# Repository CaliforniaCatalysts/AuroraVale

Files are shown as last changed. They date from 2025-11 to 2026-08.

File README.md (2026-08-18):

# Converting a 3D Printer Into an Automatic Spray Coater
aa4b74ef-185c-4f39-813c-6c8934d8dcba
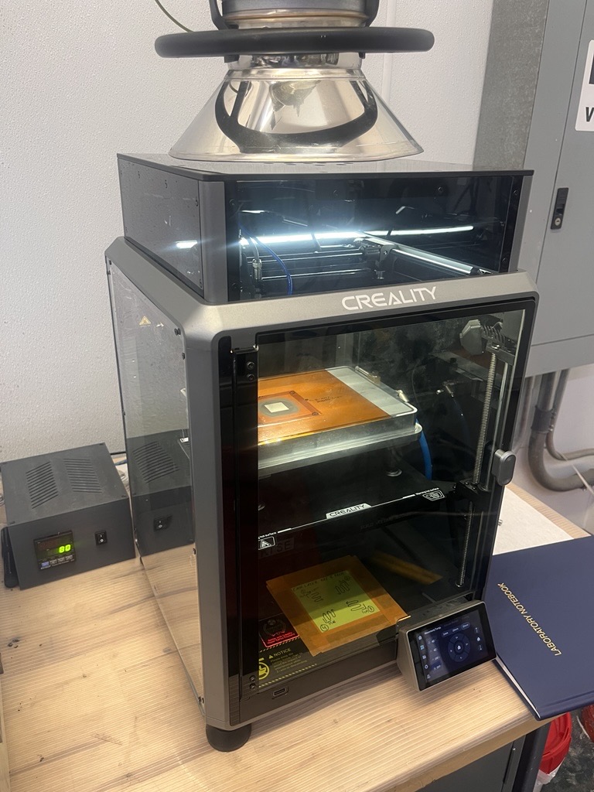
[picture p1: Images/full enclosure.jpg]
aa4b74ef-185c-4f39-813c-6c8934d8dcba

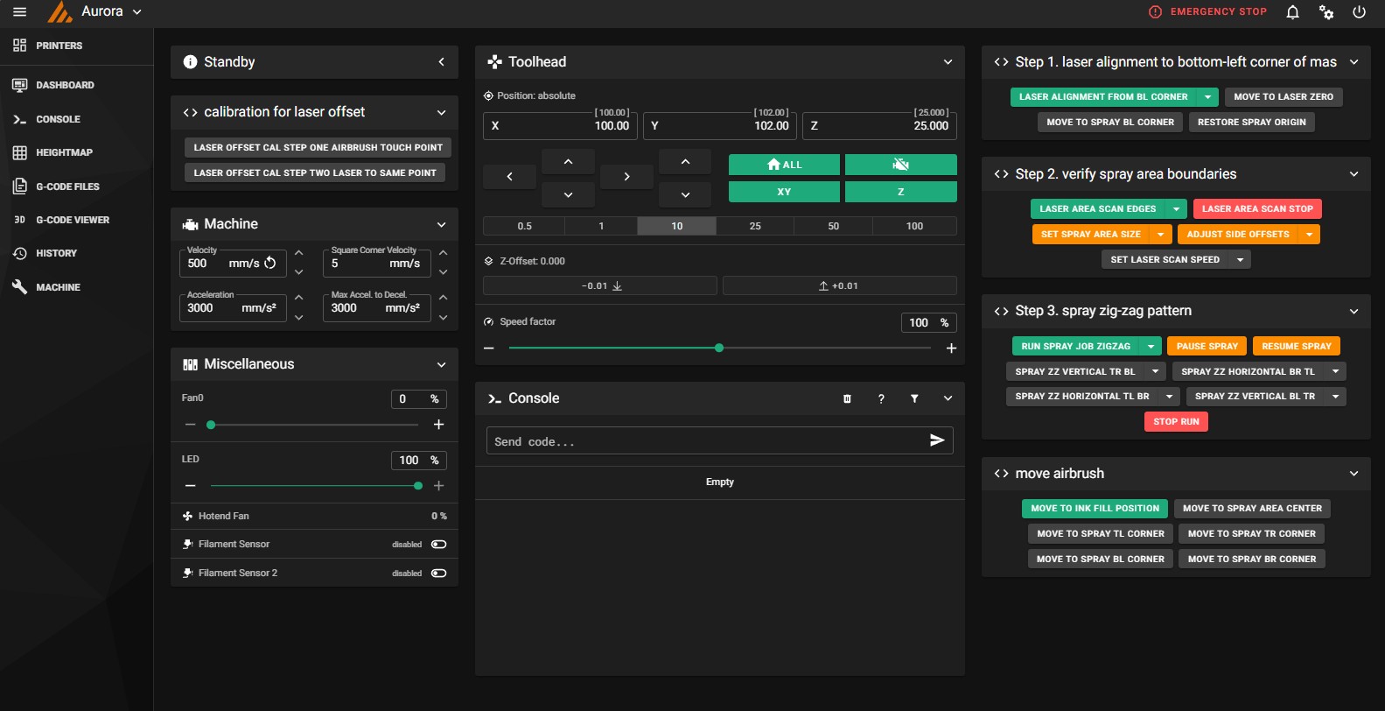
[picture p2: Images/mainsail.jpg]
mainsail web interface


This project was developed at Calicat by Steven Jaffe-Lewis, Nadia E.Tolouei, and Que Nhi Nguyen beginning in Summer 2025. 
All files and code are being released under MIT license. The team hopes that this project will be useful for other electrochemistry labs to standardize this manual airbrush process and improve loading uniformity of sprayed catalyst inks for making catalyst-coated membranes or related components.

inspired from Remi_Rafael's project: https://www.instructables.com/Converting-a-3D-Printer-Into-an-Automatic-Spray-Co/

Main changes by the team at Calicat:
 - improved the airbrush button actuation consistency and angle resolution by moving the servo arm rotation to be planar with the airbrush trigger.
 - updated stl files for mounting the airbrush onto a Creality K1 printer.
 - parameterized the spray area and path through klipper macros, enabling adjustments from within the mainsail interface.
 - added a laser crosshair used for sewing machines to precisely align the airbrush nozzle with the desired mask area.
 - built the web interface using Mainsail to control the equipment.
 - added a heated microporous vacuum board as the base.

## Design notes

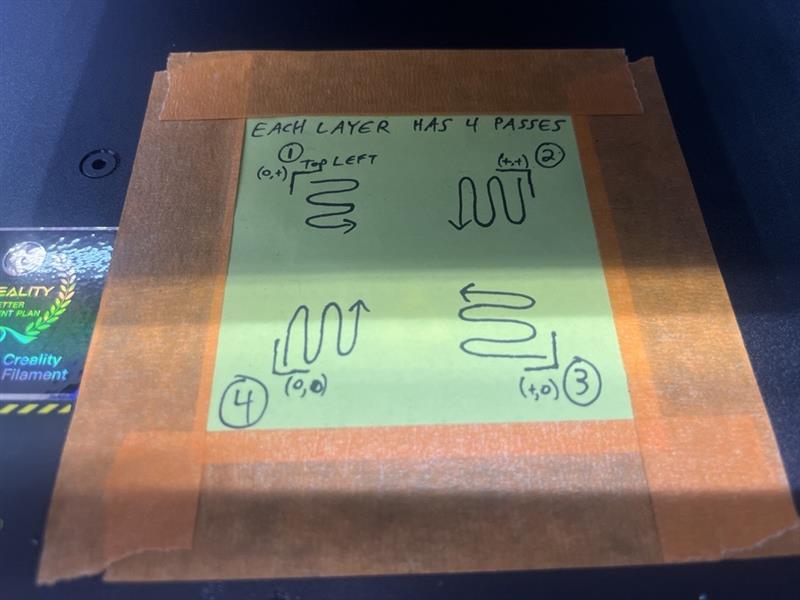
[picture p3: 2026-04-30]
Images/6f3b2e6d-e895-4d3d-af6d-b4a39b8a7106.jpg

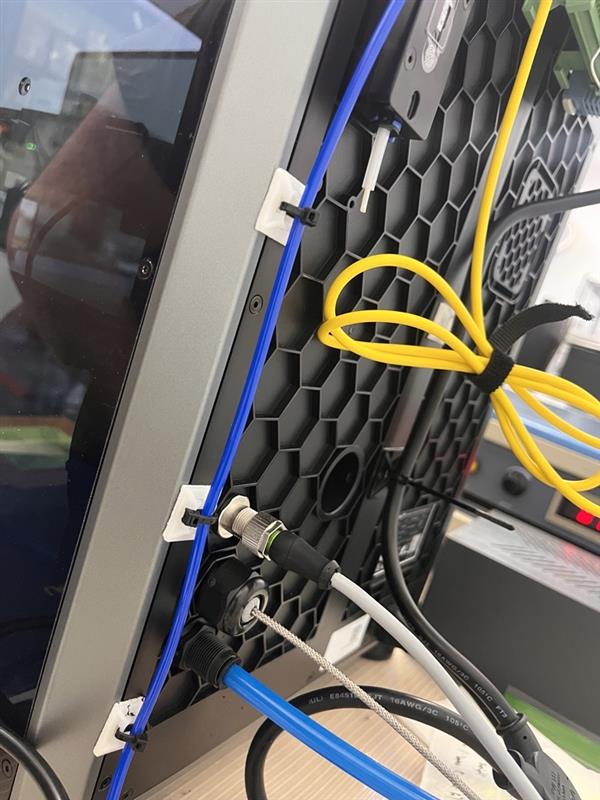
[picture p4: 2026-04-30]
Images/cb442da4-e796-43ce-a95e-fac4f4cbbab6.jpg

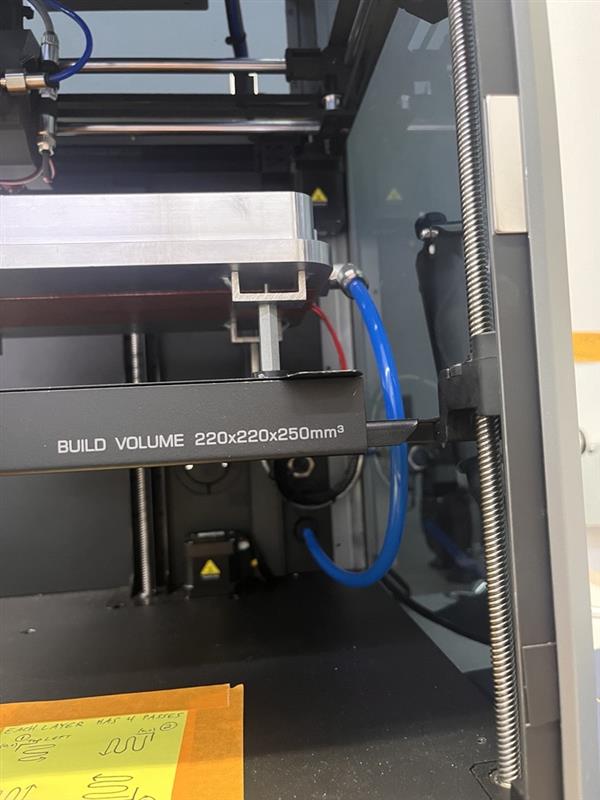
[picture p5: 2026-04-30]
Images/b7cdc5cb-0d74-4510-bfb3-8b063ddc7fe8.jpg

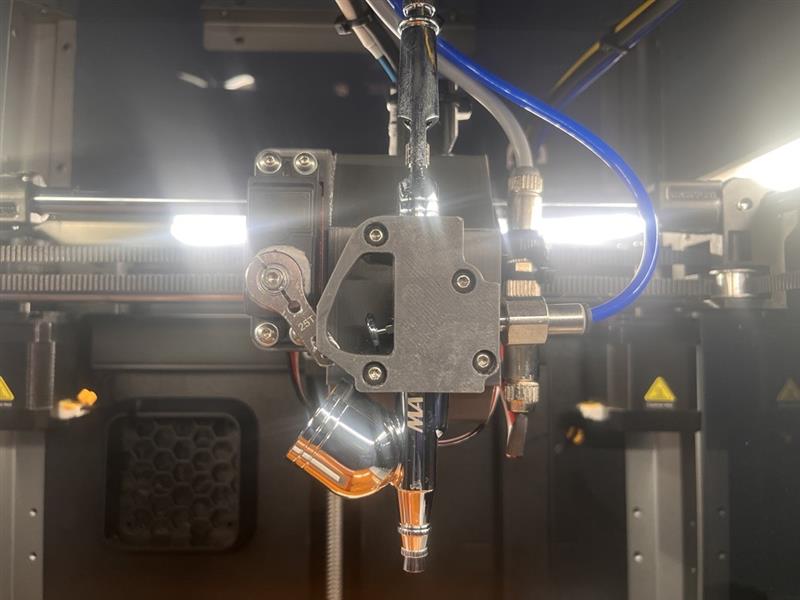
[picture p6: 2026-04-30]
Images/aa4b74ef-185c-4f39-813c-6c8934d8dcba.jpg

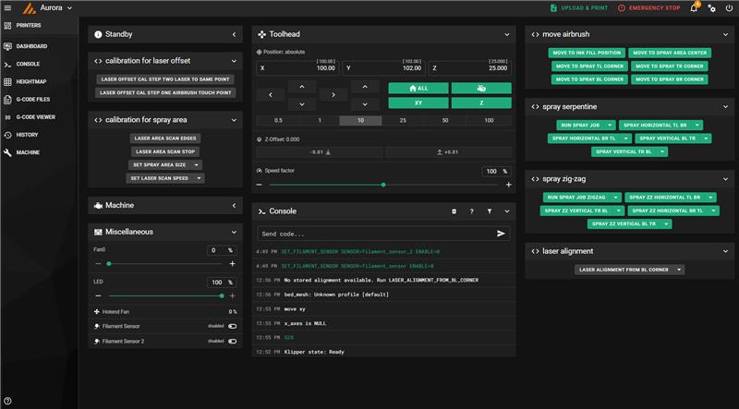
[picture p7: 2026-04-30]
Images/abf6030a-79bf-4fd6-ab85-4bce50de7b40.jpg

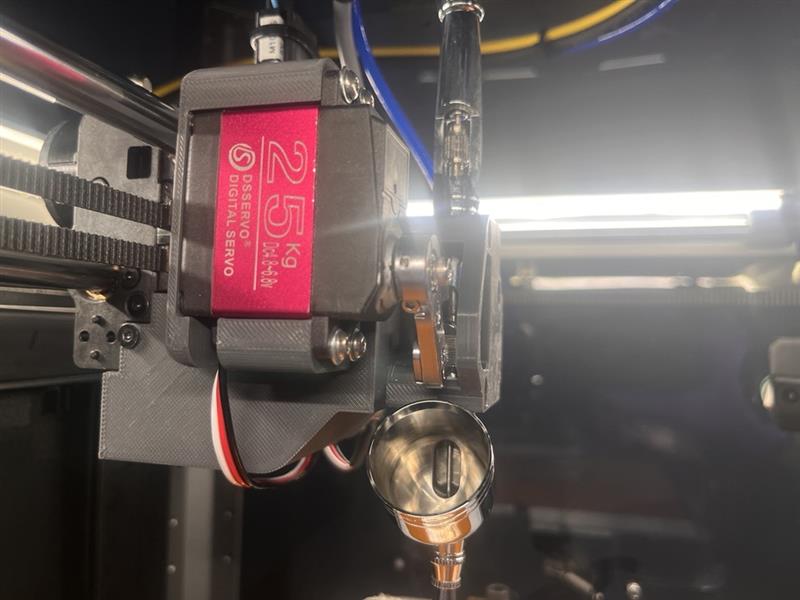
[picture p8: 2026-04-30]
Images/523d340f-f855-4a28-a0e2-c79435cb36b6.jpg

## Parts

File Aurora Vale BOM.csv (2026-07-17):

Nadia's and Nhi's Summer 2025 internship
3D Printer Modified Air Brush Spraying
Item Category | Description | Supplier | Part Number | Manufacturer | Model | Design Component | Qty Needed to Order | Unit Price | Comment | Order Status | ETA | Purchase Link
Connections | Chemical-Resistant Plastic Tubing | Mcmaster | 9388T11 |  |  |  | 10 ft | $2.70 | 1/8" ID, 1/4" OD, FEP clear tubing
Connections | Dupont Connetor |  |  |  |  | 1 | 1 | $6.98 | 40pin Male to Male, 40pin Female to Female Breadboard Jumper Ribbon Cables |  |  | https://www.amazon.com/Elegoo-EL-CP-004-Multicolored-Breadboard-arduino/dp/B01EV70C78
Control | Arduino | Amazon | A000066 |  | Arduino Elegoo Uno R3 | 2 | 1 | $13.99 | ATmega328P Microcontroller, USB-B, 7-12V input voltage |  |  | https://www.amazon.com/ELEGOO-Controller-ATmega328P-Compatible-Arduino/dp/B0B6VV7MS7
Control | Relay | DigiKey | 2066-46.61.9.024.0040-ND | Finder Relays, Inc. | 46.61.9.024.0040 |  |  | $8.43 | Relay Gen Purpose SPDT 16A 24 VDC
Control | Sensor
Control | Thermocouple | Mcmaster |  |  |  |  |  |  | Resistance Temperature Detector (RTD)
Equipment | 3D Printer | Amazon |  | Creality | K1 SE | 1 | 1 | $259.61 | Dimention 355x355x482mm, open frame, open-source | Ordered | 28-Jul | https://a.co/d/5Y77dD0
Equipment | Camera for 3D printer | Amazon |  | Creality | K1 AI | 1 | 1 | $25.23 |  | Ordered | 28-Jul | https://a.co/d/2F8gHx9
Equipment | Vacuum Table | Clampus | MP2216M | Clampus |  | 1 | 0 | $484.33 |  | In stock |  | Vacuum Table MP2216M - 8.66 x 6.30 in. - ClampuSystems
Equipment | Control Heater |  |  |  |  | 1 | 1 |  |  | Ordered
Equipment | DC/DC converter | Amazon |  | HiLetgo | LM2596 DC-DC | 1 |  | $10.48 | Adjustable DC/DC step down converter 4.0-40V to 1.25-37V |  |  | https://www.amazon.com/HiLetgo-Step-down-Converter-1-25-37V-Voltmeter/dp/B00LSEBYHU/ref=sr_1_8?
Equipment | Airbrush | Amazon |  |  | G233 Pro | 1 | 1 | $39.99 | 0.2, 0.3 & 0.5mm Needles, 1/3 oz Cup |  |  | https://www.amazon.com/Master-Airbrush-Multi-Purpose-Dual-Action-Professional/dp/B002KJDXHQ
Equipment | Compressor | Amazon |  | TIMBERTECH | AS18-2 |  | 1 | $66.79 | 120 VAC, 4 bar Auto Stop |  |  | https://www.amazon.com/dp/B07VSFZVRH?sp_csd=d2lkZ2V0TmFtZT1zcF9kZXRhaWxfdGhlbWF0aWM
Equipment | DC Servo Motor | DigiKey | 1738-SER0064-ND | DFRobot | SER0064 | 2 |  | $21.90 | Positional Rotation DC Motor Gearmotor 52 RPM 5 ~ 8.4VDC | Ordered |  | https://www.digikey.com/en/products/detail/dfrobot/SER0064/23028651
Miscellaneous | LED light stip | Amazon |  |  |  | 1 | 16.4 ft | $19.99 | Uniform Light 9W, 480LED/m, Cool White, IP65 (water resistance), 24 VDC |  |  | https://www.amazon.com/gp/product/B08VWXPQYP/ref=ox_sc_act_title_4?smid=A35UAT07QG3EC6&th=1
 |  |  |  |  |  |  |  | $960.42

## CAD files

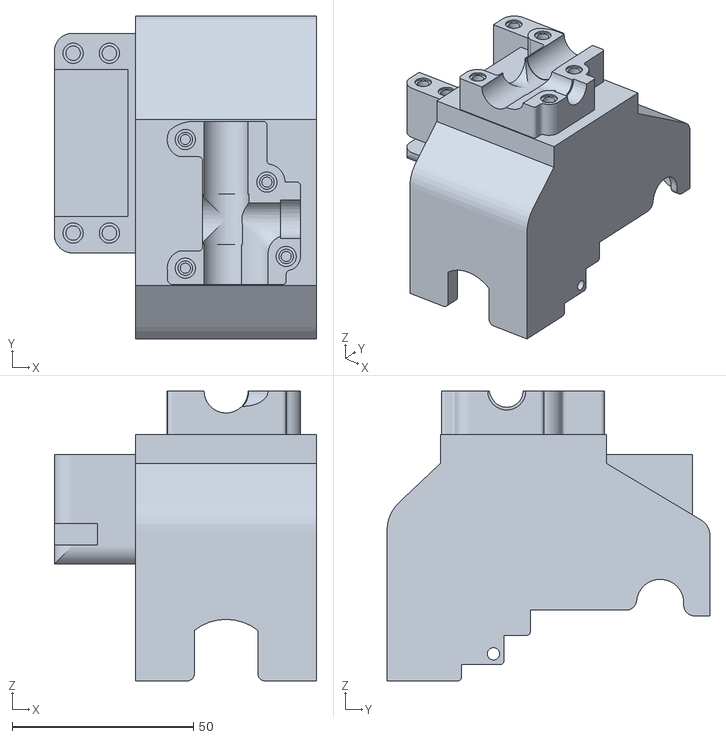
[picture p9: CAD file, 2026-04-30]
Airbrush_mount/Airbrush_mount_STLfiles/Airbrush Mount Assembly.STL
72.4 x 89.1 x 80.0

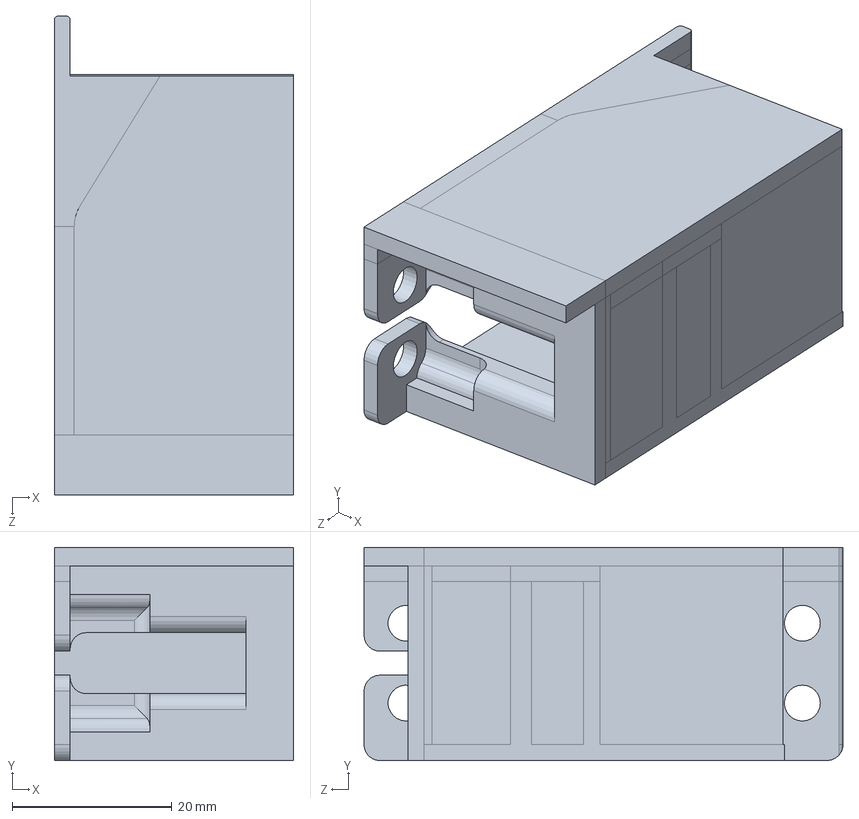
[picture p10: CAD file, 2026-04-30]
Airbrush_mount/Airbrush_mount_Solidworks/Servo Mount.SLDPRT
30.0 x 26.7 x 60.0 mm

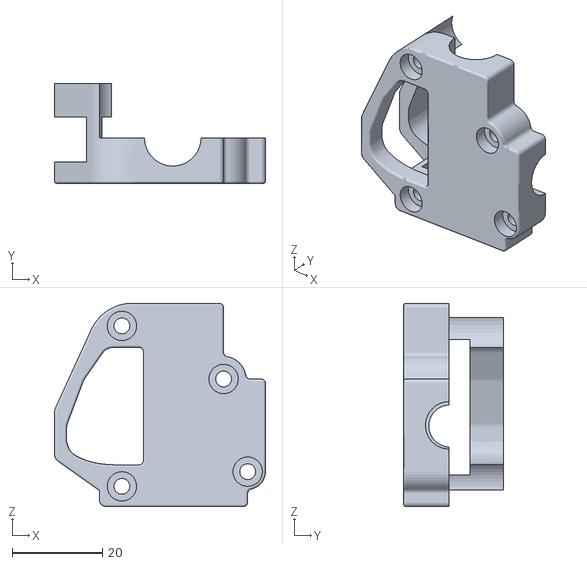
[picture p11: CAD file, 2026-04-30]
Airbrush_mount/Airbrush_mount_STLfiles/Airbrush Cover.STL
46.7 x 22.1 x 45.0

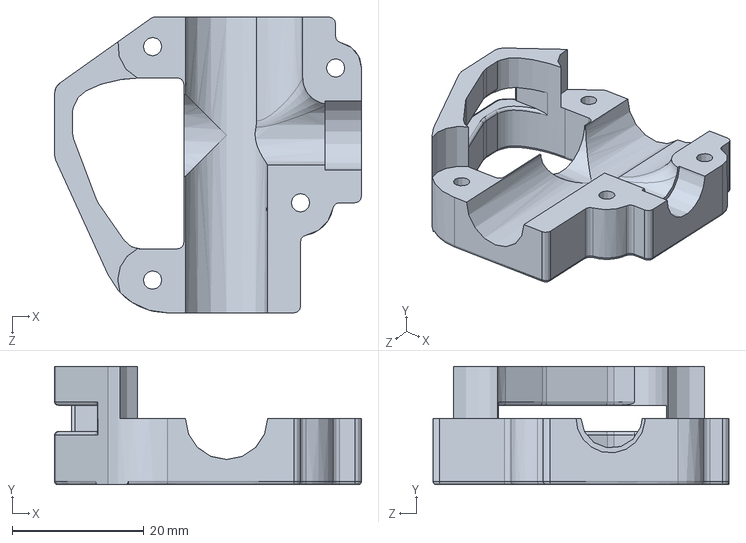
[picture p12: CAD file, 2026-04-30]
Airbrush_mount/Airbrush_mount_Solidworks/hmc mod_Spray_pen_holder_part_2_JT_new.SLDPRT
46.7 x 18.0 x 45.0 mm

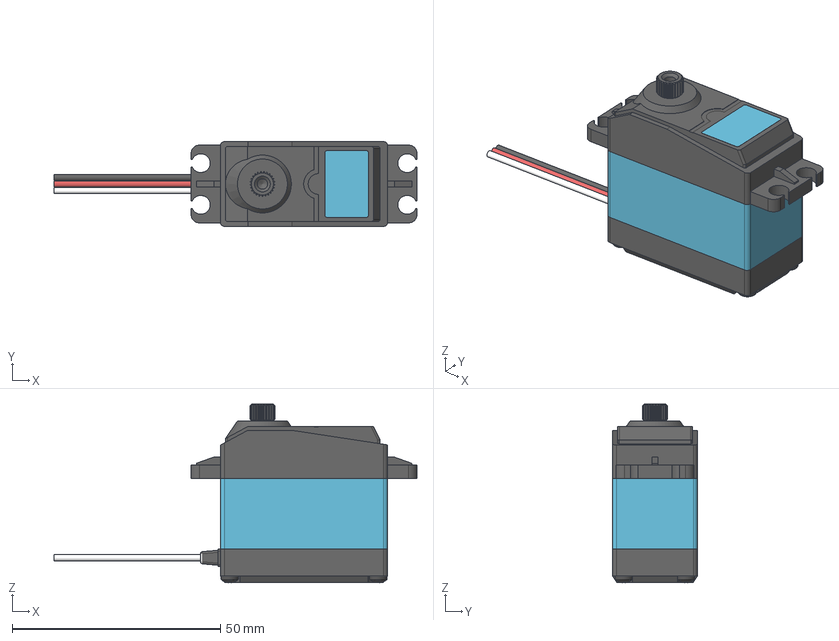
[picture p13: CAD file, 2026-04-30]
Airbrush_mount/Airbrush_mount_Solidworks/DS3225MG Servo 25Kg 4.8-6.8V.stp
87.3 x 20.4 x 42.9 mm
DS3225MG Servo 25Kg 4.8-6.8V B
DS3225MG Servo 25Kg 4.8-6.8V A
DS3225MG Servo 25Kg 4.8-6.8V C

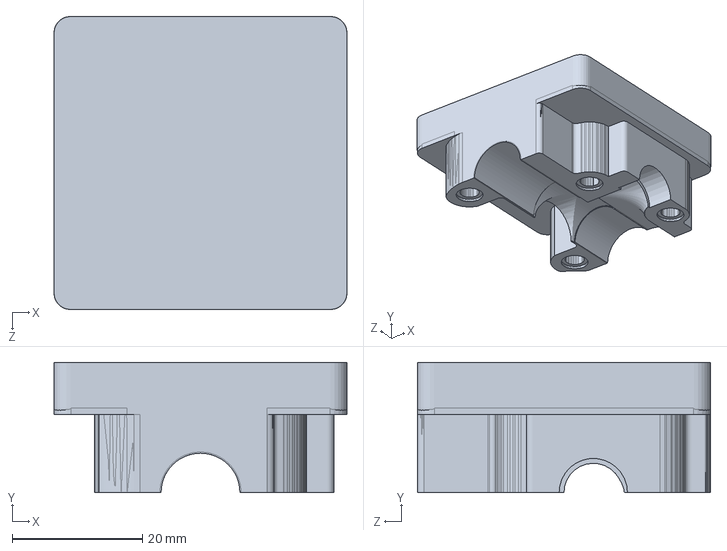
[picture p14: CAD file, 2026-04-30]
Airbrush_mount/Airbrush_mount_Solidworks/Spray_pen_holder_part_1_M3inserts.SLDPRT
45.0 x 20.0 x 45.0 mm

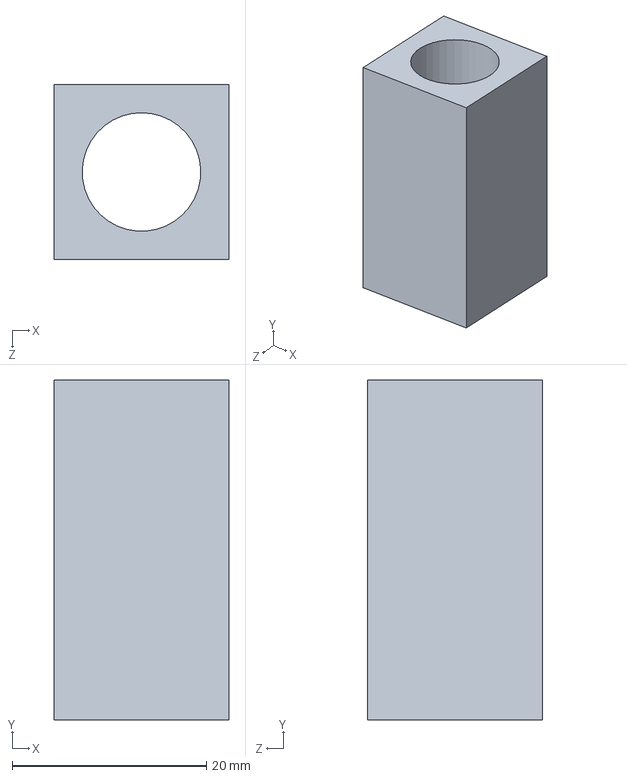
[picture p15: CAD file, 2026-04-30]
Airbrush_mount/Airbrush_mount_Solidworks/laser mount.SLDPRT
18.0 x 35.0 x 18.0 mm

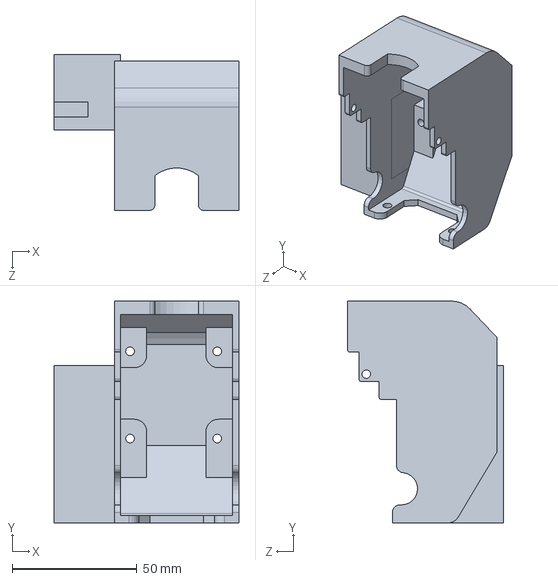
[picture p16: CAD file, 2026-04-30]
Airbrush_mount/Airbrush_mount_Solidworks/Creality K1 Print Head Cover1.SLDPRT
74.2 x 89.1 x 62.5 mm

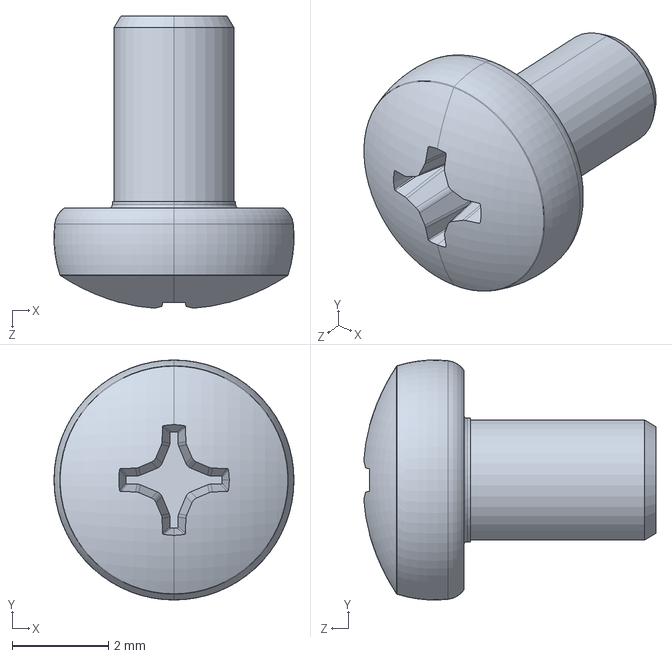
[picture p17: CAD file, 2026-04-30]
Airbrush_mount/Airbrush_mount_Solidworks/95836A251_NO THREADS_Black-Oxide 18-8 Stainless Steel Pan Head Phillips Screws.SLDPRT
5.00 x 5.00 x 6.08 mm

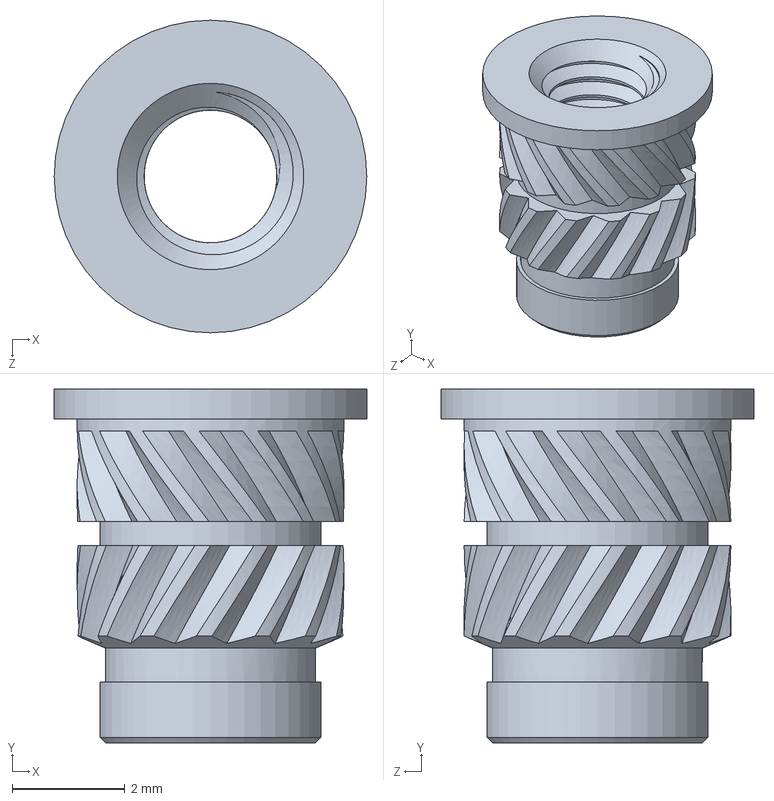
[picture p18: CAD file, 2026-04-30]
Airbrush_mount/Airbrush_mount_Solidworks/97171A310_Brass Heat-Set Inserts for Plastic.SLDPRT
5.54 x 6.27 x 5.54 mm

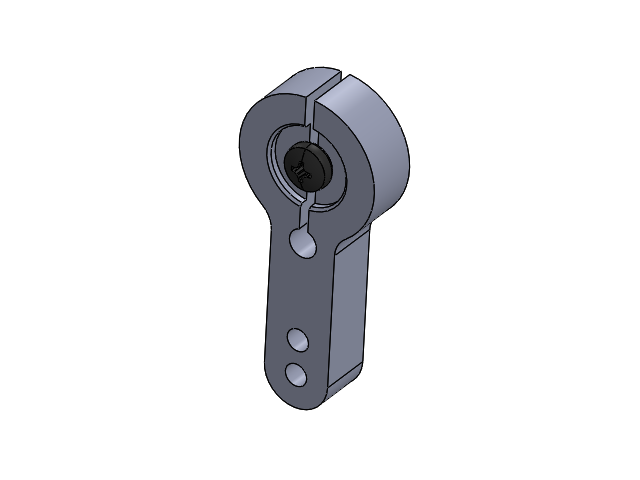
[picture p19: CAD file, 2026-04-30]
Airbrush_mount/Airbrush_mount_Solidworks/Servo Rotating Arm.SLDASM
Servo Rotating Arm^Servo Rotating Arm
95836A251_NO THREADS_Black-Oxide 18-8 Stainless Steel Pan Head Phillips Screws

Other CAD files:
Airbrush_mount/Airbrush_mount_STLfiles/Laser Mount.STL
Airbrush_mount/Airbrush_mount_Solidworks/DS3225MG Servo 25Kg 4.8-6.8V.SLDASM

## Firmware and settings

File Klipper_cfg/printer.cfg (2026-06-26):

# K1C
# Printer_size: 220x220x250
# Version: v2.0.8
# CreateDate: 2023/09/05
# Nozzle_mcu: chip: GD32F303CBT6
#             version: CR-K1-MAX-NOZZLE-V1.2.0
# Leveling_mcu: chip: GD32E230F8P6
#             version: CR-K1-MAX-LEVELING-V1.1.0
# mcu: chip: GD32F303RET6
#      version: CR4CU220812S12

[include sensorless.cfg]
[include printer_params.cfg]

[include gcode_macro.cfg]

[include aurora_spray.cfg]
[include aurora_move_to.cfg]
[include aurora_laser.cfg]
[include aurora_calibrations.cfg]
[include aurora_spray_zigzag.cfg]
#[include aurora_spray_calibration.cfg]

[mcu]
serial: /dev/ttyS7
baud: 230400
restart_method: command

[mcu nozzle_mcu]
serial: /dev/ttyS1
baud: 230400
restart_method: command

[mcu leveling_mcu]
serial: /dev/ttyS9
baud: 230400
restart_method: command

[verify_heater extruder]
[verify_heater heater_bed]
check_gain_time: 120
heating_gain: 1.0
hysteresis: 10

[mcu rpi]
serial: /tmp/klipper_host_mcu

[bl24c16f]
i2c_mcu: rpi
i2c_bus: i2c.2
i2c_speed: 400000

[idle_timeout]
timeout: 99999999

[virtual_sdcard]
path: /usr/data/printer_data/gcodes

[gcode_arcs]
resolution: 1.0

[temperature_sensor mcu_temp]
sensor_type: temperature_mcu
min_temp: 0
max_temp: 100

# [temperature_sensor chamber_temp]
# sensor_type: EPCOS 100K B57560G104F
# sensor_pin: PC5
# min_temp: 0
# max_temp: 125

# [duplicate_pin_override]
# pins: PC0, PC5

# [temperature_fan chamber_fan]
# pin: PC0
# cycle_time: 0.0100
# hardware_pwm: false
# max_power: 1
# shutdown_speed: 0
# sensor_type: EPCOS 100K B57560G104F
# sensor_pin: PC5
# min_temp: 0
# max_temp: 70
# control: watermark
# max_delta: 2
# target_temp: 35.0
# max_speed: 1.0
# min_speed: 0.0

[stepper_x]
step_pin: PC2
dir_pin: !PB9
enable_pin: !PC3
microsteps: 32
rotation_distance: 40
endstop_pin: tmc2209_stepper_x:virtual_endstop
position_endstop: 174.5
position_min: 10
position_max: 175
homing_speed: 30
homing_retract_dist:0

[tmc2209 stepper_x]
uart_pin:PA9
interpolate: True
run_current:1.5
hold_current:1.0
sense_resistor: 0.100
stealthchop_threshold: 0
uart_address:3
diag_pin: ^PB12
# driver_IHOLDDELAY: 8
# driver_TPOWERDOWN: 20
# driver_TBL: 1
# driver_TOFF: 1
# driver_HEND: 0
# driver_HSTRT: 7
driver_SGTHRS: 75

[stepper_y]
step_pin: PB8
dir_pin: !PB7
enable_pin: !PC3
microsteps: 32
rotation_distance: 40
endstop_pin: tmc2209_stepper_y:virtual_endstop
position_endstop: 10.5
position_min: 10
position_max: 170
homing_speed: 30
homing_retract_dist:0

[tmc2209 stepper_y]
uart_pin:PA10
interpolate: True
run_current:1.5
hold_current:1.0
sense_resistor: 0.100
stealthchop_threshold: 0
uart_address:3
diag_pin: ^PB13
# driver_IHOLDDELAY: 8
# driver_TPOWERDOWN: 20
# driver_TBL: 1
# driver_TOFF: 1
# driver_HEND: 0
# driver_HSTRT: 7
driver_SGTHRS: 75

[stepper_z]
step_pin: PB6
dir_pin: !PB5
enable_pin: !PC3
microsteps: 16
rotation_distance:8
gear_ratio: 64:20
endstop_pin: tmc2209_stepper_z:virtual_endstop# PA15   #probe:z_virtual_endstop
position_endstop: 8
position_max: 120
position_min: 0

[tmc2209 stepper_z]
uart_pin: PA11
uart_address: 3
run_current: 0.8
diag_pin: ^PB14
stealthchop_threshold: 0
sense_resistor: 0.100
# driver_IHOLDDELAY: 8
# driver_TPOWERDOWN: 20
# driver_TBL: 1
# driver_TOFF: 1
# driver_HEND: 2
# driver_HSTRT: 2
driver_SGTHRS: 0

[extruder]
max_extrude_only_distance: 1000.0
max_extrude_cross_section: 80
step_pin: nozzle_mcu:PB1
dir_pin: nozzle_mcu:PB0
enable_pin: !nozzle_mcu:PB2
microsteps: 16
rotation_distance: 6.9
nozzle_diameter: 0.400
filament_diameter: 1.750
heater_pin: nozzle_mcu:PB7
sensor_type: EPCOS 100K B57560G104F
sensor_pin: nozzle_mcu:PA0
pressure_advance: 0.04
pressure_advance_smooth_time: 0.040
control: pid
pid_Kp: 25.013
pid_Ki: 2.566
pid_Kd: 60.966
min_temp: 0
max_temp: 320

[tmc2209 extruder]
uart_pin: nozzle_mcu:PB11
tx_pin: nozzle_mcu:PB10

uart_address: 3
run_current: 0.55
sense_resistor: 0.150
stealthchop_threshold: 0
# driver_IHOLDDELAY: 8
# driver_TPOWERDOWN: 20
# driver_TBL: 2
# driver_TOFF: 3
# driver_HEND: 0
# driver_HSTRT: 5

[heater_bed]
heater_pin: PB10
sensor_type: EPCOS 100K B57560G104F
sensor_pin: PC4
control: watermark
# control: pid
# pid_kp: 27
# pid_ki: 0.08
# pid_kd: 0
min_temp: 0
max_temp: 115

[filament_switch_sensor filament_sensor]
pause_on_runout: true
switch_pin: !PC15
runout_gcode:
  {% if printer.extruder.can_extrude|lower == 'true' %}
    G91
    G0 E30 F600
    G90
  {% endif %}

[filament_switch_sensor filament_sensor_2]
pause_on_runout: true
switch_pin: !nozzle_mcu:PA10

[multi_pin heater_fans]
pins:nozzle_mcu:PB5,PB2

[heater_fan hotend_fan]
pin: multi_pin:heater_fans
heater: extruder
heater_temp: 40

[static_digital_output my_fan_output_pins]
pins: nozzle_mcu: PB6

[output_pin fan0]
pin: !nozzle_mcu: PB8
pwm: True
cycle_time: 0.0100
hardware_pwm: false
value: 0.00
scale: 255
shutdown_value: 0.0

# [output_pin fan1]
# pin: PC0
# pwm: True
# cycle_time: 0.0100
# hardware_pwm: false
# value: 0.00
# scale: 255
# shutdown_value: 0.0

# [output_pin fan2]
# pin: PB1
# pwm: True
# cycle_time: 0.0100
# hardware_pwm: false
# value: 0.00
# scale: 255
# shutdown_value: 0.0

[output_pin LED]
pin:PB0
pwm: True
cycle_time: 0.010
value: 1

[adxl345]
cs_pin: nozzle_mcu:PA4
spi_speed: 5000000
axes_map: x,-z,y
spi_software_sclk_pin: nozzle_mcu:PA5
spi_software_mosi_pin: nozzle_mcu:PA7
spi_software_miso_pin: nozzle_mcu:PA6

[resonance_tester]
accel_chip: adxl345
accel_per_hz: 75
# min_freq: 30
# max_freq: 100
probe_points:
   110,110,10

[prtouch_v2]  # K1
pr_version: 1
step_base: 2
z_offset: 0 
noz_ex_com: 0.06
tilt_corr_dis: 0
tri_min_hold: 2500
tri_max_hold: 6000
pres_cnt: 4
pres0_clk_pins: leveling_mcu:PA5
pres0_sdo_pins: leveling_mcu:PA1
pres1_clk_pins: leveling_mcu:PA2
pres1_sdo_pins: leveling_mcu:PA0
pres2_clk_pins: leveling_mcu:PA6
pres2_sdo_pins: leveling_mcu:PA3
pres3_clk_pins: leveling_mcu:PA7
pres3_sdo_pins: leveling_mcu:PA4
show_msg: False
step_swap_pin: PC10
pres_swap_pin: leveling_mcu:PB1
g28_wait_cool_down: true
pa_clr_down_mm: -0.15
clr_noz_start_x: 87
clr_noz_start_y: 225
clr_noz_len_x: 46
clr_noz_len_y: 1
speeds: 2.5,1.0
tri_hftr_cut: 2,1
tri_lftr_k1: 0.70,0.30
tri_try_max_times: 10
tri_min_hold: 2500,20000
tri_max_hold: 6000,60000

clr_noz_quick: true
clr_quick_high:0.7
clr_xy_quick_spd:100
clr_quick_times:10
clr_quick_react_dis:5

[bed_mesh]
speed: 150
mesh_min: 5,5
mesh_max: 215,215
probe_count: 5,5
fade_start: 5.0
fade_end: 50.0

[display_status]

[printer]
kinematics: corexy
max_velocity: 600
max_accel: 3000 #20000 default
max_accel_to_decel: 3000 #20000 default
max_z_velocity: 10
square_corner_velocity: 5.0 #5.0 default
max_z_accel: 300
square_corner_max_velocity: 200.0
[pause_resume]
# recover_velocity: 500.

[exclude_object]

[respond]
default_type: echo
default_prefix: 

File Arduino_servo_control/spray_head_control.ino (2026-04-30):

#include <Servo.h>
Servo SprayHead;
// Set the Servo angles (adjust in 1-5 deg increments): 
//      CW rotation  [less ink spray] = decrease Set_ON angle number
//      CCW rotation [more ink spray] = increase Set_ON angle number
const int Set_ON = 156; //angle when spray is on.
//-------------------------------------------------------------------

const int Set_OFF = 125; //angle when spray is off.

bool Enable_Pot_Influence = 0; //set to 1 to enable the external dial adjustment for the ON angle. Normally set to 0 to disable
const int Pot_Max_Influence = 20;

int Previous_Influence_Angle = 0;
int Current_Influence_Angle = 0;

const int MAX_ON = 170; //max allowable angle for on position
const int MIN_OFF = 90; //min allowable angle for off position

int A_OFF = Set_OFF; //actual angle value sent to servo
int A_ON = Set_ON; //actual angle value sent to servo
bool PreviousSprayState = 0;
bool CurrentSprayState = 0;

//Servo angle calibration
float angle_adjust = 0.75; //180deg signal = 225deg actual 

// Analog input pin
int M106_Input_Pin = A5;      // Controls Servo and LED
int Pot_Input_Pin = A1;   //External position dial Analog Input[4-20ma signal generator]

// Output pins
int servoPin = 10;      // Servo control pin

// Sensor values
float M106_Input_Reading = 0;
float M106_Input_Voltage = 0;
int M106_int = 0;
int Pot_Input = 0;
int Pot_Angle_Influence = 0;


int delayValue = 50;

void setup() {
  Serial.begin(9600);
  Serial.println("--------------------------------------");
  Serial.println("Airbrush Control Servo program started");
  Serial.println("--------------------------------------");

  Serial.print("Angle_ON: ");Serial.print(A_ON); Serial.print("    Angle_OFF: ");Serial.println(A_OFF);
  //Serial.print("angle_adjust: ");Serial.println(angle_adjust);
  if(Enable_Pot_Influence == 1) { Serial.print("Attention: External angle ON adjustment dial is LIVE. "); Serial.print("Current angle adjustment value: ");Serial.println(Pot_Angle_Influence);Serial.println("Note: Servo angles direction CW=lower angle, CCW=higher angle");}
  Serial.println("--------------------------------------\n");
  SprayHead.attach(servoPin);
  SprayHead.write(A_OFF * angle_adjust); // Start in OFF position
  Serial.print(" spray is OFF    ");Serial.println(A_OFF);
}

void loop() {
    // Read analog voltage from A5
  M106_Input_Reading = analogRead(M106_Input_Pin);
  M106_Input_Voltage = round((M106_Input_Reading / 1023.0) * 5.0); //scale 0-5V
  
  if (Enable_Pot_Influence == 1) {
    // Read extenal angle influence from pot. Max CW = 0. Max CCW = 674. Mid = 312.
    Pot_Input = analogRead(Pot_Input_Pin);
    Pot_Angle_Influence = (Pot_Input - 312) * Pot_Max_Influence / 312;
    if (Pot_Angle_Influence > Pot_Max_Influence) { Pot_Angle_Influence = Pot_Max_Influence;}
    if (Pot_Angle_Influence < (-1 * Pot_Max_Influence)) { Pot_Angle_Influence = (-1 * Pot_Max_Influence);}
    Current_Influence_Angle = Pot_Angle_Influence;

    if (Current_Influence_Angle != Previous_Influence_Angle) {
      if (CurrentSprayState == 1) {
        Serial.print("Pot_Input_Value:"); Serial.print(Pot_Input); Serial.print("  Pot_Angle_Influence:"); Serial.print(Pot_Angle_Influence); 
        A_ON = round(Set_ON + Pot_Angle_Influence); //change setpoint of A_ON
        Serial.print("   A_ON:");Serial.print(A_ON);
        if (A_ON > MAX_ON) {
          A_ON = MAX_ON;
          Serial.print(" limited to MAX_ON ");Serial.println(MAX_ON);
        }
        else {Serial.println();}
        SprayHead.write(A_ON * angle_adjust);   // Set Servo to new Spray ON angle 
        Previous_Influence_Angle = Current_Influence_Angle; 
      }
    }
  }


  // Control spray head and LED
    //Serial.print("M106_Input_Voltage: ");Serial.println(M106_Input_Voltage);
    M106_int = round(M106_Input_Voltage);
    //Serial.print("M106_int: ");Serial.println(M106_int);
  if (M106_int > 3) {
    CurrentSprayState = 1; //if Spray is ON
    if (CurrentSprayState != PreviousSprayState) { //|| (abs(Current_Influence_Angle - Previous_Influence_Angle) > 2 )); {
      SprayHead.write(A_ON * angle_adjust);   // Set Servo to Spray ON
      Serial.print(" spray is ON     ");Serial.println(A_ON);
    }
  } else {
    CurrentSprayState = 0;
    if (CurrentSprayState != PreviousSprayState) {
      SprayHead.write(A_OFF * angle_adjust);     // Set Servo to Spray OFF
      Serial.print(" spray is OFF    ");Serial.println(A_OFF);
    }
  }
  PreviousSprayState = CurrentSprayState;

  delay(delayValue); // Wait before next reading
}

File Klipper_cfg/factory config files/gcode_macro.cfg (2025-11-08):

# K1C
# CreateDate: 2023/09/05


[gcode_macro PRINTER_PARAM]
variable_z_safe_pause: 0.0
variable_z_safe_g28: 3.0
variable_max_x_position: 220.0
variable_max_y_position: 140.0
variable_max_z_position: 250.0
variable_fans: 1
variable_auto_g29: 0
variable_fan0_min: 25
variable_fan1_min: 50
variable_fan2_min: 180
variable_fan2_speed: 0
variable_hotend_temp: 0
variable_e_min_current: 0.27
gcode:

[gcode_macro AUTOTUNE_SHAPERS]
variable_autotune_shapers: 'ei'
gcode:

[gcode_macro LOAD_MATERIAL_CLOSE_FAN2]
variable_fan2_value: 0
gcode:
  SAVE_GCODE_STATE NAME=myMoveState
#   {% if printer['output_pin fan2'].value > 0.0 %}
#     SET_GCODE_VARIABLE MACRO=LOAD_MATERIAL_CLOSE_FAN2 VARIABLE=fan2_value VALUE={printer['output_pin fan2'].value}
#     M107 P2
#   {% endif %}
  RESTORE_E_CURRENT

[gcode_macro LOAD_MATERIAL_RESTORE_FAN2]
gcode:
#   {% set fan2_value = printer['gcode_macro LOAD_MATERIAL_CLOSE_FAN2'].fan2_value|float %}
  RESTORE_GCODE_STATE NAME=myMoveState
#   {% if fan2_value > 0.0 %}
#     {% set s_value = (fan2_value * 255 - printer["gcode_macro PRINTER_PARAM"].fan2_min) * 255 / (255 - printer["gcode_macro PRINTER_PARAM"].fan2_min) %}
#     M106 P2 S{s_value}
#     SET_GCODE_VARIABLE MACRO=LOAD_MATERIAL_CLOSE_FAN2 VARIABLE=fan2_value VALUE=0
#   {% endif %}
  SET_E_MIN_CURRENT

[gcode_macro SET_E_MIN_CURRENT]
gcode:
  {% set e_current = printer['gcode_macro PRINTER_PARAM'].e_min_current %}
  M400
  SET_TMC_CURRENT STEPPER=extruder CURRENT={e_current} HOLDCURRENT={e_current}
  G4 P2000

[gcode_macro RESTORE_E_CURRENT]
gcode:
  {% set e_current = printer.configfile.settings['tmc2209 extruder'].run_current %}
  M400
  SET_TMC_CURRENT STEPPER=extruder CURRENT={e_current} HOLDCURRENT={e_current}
  G4 P2000

[gcode_macro LOAD_MATERIAL]
gcode:
  LOAD_MATERIAL_CLOSE_FAN2
  M109 S{printer.custom_macro.default_extruder_temp}
  G91
  G1 E80 F180
  LOAD_MATERIAL_RESTORE_FAN2

[gcode_macro QUIT_MATERIAL]
gcode:
  SAVE_GCODE_STATE NAME=myMoveState
  RESTORE_E_CURRENT
  M109 S{printer.custom_macro.default_extruder_temp}
  M83
  G1 E100 F300
  G1 E-15 F3000
  G1 E-22.4700 F2400
  G1 E-6.4200 F1200
  G1 E-3.2100 F720
  G1 E5.0000 F356
  G1 E-5.0000 F384
  G1 E5.0000 F412
  G1 E-5.0000 F440
  G1 E5.0000 F467
  G1 E-5.0000 F495
  G1 E5.0000 F523
  G1 E-5.0000 F3000
  G1 E-15 F3000
  SET_E_MIN_CURRENT
  RESTORE_GCODE_STATE NAME=myMoveState

[gcode_macro Qmode]
variable_flag: 0
variable_accel: 0
variable_accel_to_decel: 0
variable_velocity: 0
variable_square_corner_velocity: 0
variable_pressure_advance:0.0
variable_fan0_value: 0.00
variable_fan1_value: 0.00
variable_fan2_value: 0.00
variable_speed_factor: 0
variable_max_accel: 2500
variable_max_accel_to_decel: 2500
gcode:
  {% set printer_state = printer.print_stats.state %}
  {% if printer['gcode_macro Qmode'].flag|int == 0 %}
    {% if printer_state == "printing" or printer_state == "paused" %}
      SET_GCODE_VARIABLE MACRO=Qmode VARIABLE=accel VALUE={printer.toolhead.max_accel}
      SET_GCODE_VARIABLE MACRO=Qmode VARIABLE=accel_to_decel VALUE={printer.toolhead.max_accel_to_decel}
      SET_GCODE_VARIABLE MACRO=Qmode VARIABLE=velocity VALUE={printer.toolhead.max_velocity}
      SET_GCODE_VARIABLE MACRO=Qmode VARIABLE=square_corner_velocity VALUE={printer.toolhead.square_corner_velocity}
      SET_GCODE_VARIABLE MACRO=Qmode VARIABLE=pressure_advance VALUE={printer.extruder.pressure_advance}
      SET_GCODE_VARIABLE MACRO=Qmode VARIABLE=speed_factor VALUE={printer.gcode_move.speed_factor}
      SET_GCODE_VARIABLE MACRO=Qmode VARIABLE=fan0_value VALUE={printer['output_pin fan0'].value}
    #   SET_GCODE_VARIABLE MACRO=Qmode VARIABLE=fan1_value VALUE={printer['output_pin fan1'].value}
    #   SET_GCODE_VARIABLE MACRO=Qmode VARIABLE=fan2_value VALUE={printer['output_pin fan2'].value}
      SET_TMC_FIELD STEPPER=stepper_x FIELD=en_spreadcycle VALUE=0
      SET_TMC_FIELD STEPPER=stepper_y FIELD=en_spreadcycle VALUE=0

      SET_TMC_CURRENT STEPPER=stepper_x CURRENT=1.0 
      SET_TMC_CURRENT STEPPER=stepper_y CURRENT=1.0 
      G4 P1000

      # Set Motion Parameters
      SET_VELOCITY_LIMIT ACCEL=2500
      SET_VELOCITY_LIMIT ACCEL_TO_DECEL=2500
      SET_VELOCITY_LIMIT VELOCITY=150
      SET_VELOCITY_LIMIT SQUARE_CORNER_VELOCITY=5
      SET_PRESSURE_ADVANCE ADVANCE=0.05
      M220 S50

      {% set tmp = printer['output_pin fan0'].value * 255 %}
      SET_GCODE_VARIABLE MACRO=Qmode VARIABLE=fan0_value VALUE={tmp}
      {% if tmp - printer['gcode_macro PRINTER_PARAM'].fan0_min > (255 - printer['gcode_macro PRINTER_PARAM'].fan0_min) / 2 %}
        {% set tmp = printer['gcode_macro PRINTER_PARAM'].fan0_min + (255 - printer['gcode_macro PRINTER_PARAM'].fan0_min) / 2 %}
        SET_PIN PIN=fan0 VALUE={tmp}
      {% endif %}

    #   {% set tmp = printer['output_pin fan1'].value * 255 %}
    #   SET_GCODE_VARIABLE MACRO=Qmode VARIABLE=fan1_value VALUE={printer['output_pin fan1'].value * 255}
    #   {% if tmp - printer['gcode_macro PRINTER_PARAM'].fan1_min > (255 - printer['gcode_macro PRINTER_PARAM'].fan1_min) / 2 %}
    #     {% set tmp = printer['gcode_macro PRINTER_PARAM'].fan1_min + (255 - printer['gcode_macro PRINTER_PARAM'].fan1_min) / 2 %}
    #     SET_PIN PIN=fan1 VALUE={tmp}
    #   {% endif %}

    #   {% set tmp = printer['output_pin fan2'].value * 255 %}
    #   SET_GCODE_VARIABLE MACRO=Qmode VARIABLE=fan2_value VALUE={printer['output_pin fan2'].value * 255}
    #   {% if tmp - printer['gcode_macro PRINTER_PARAM'].fan2_min > (255 - printer['gcode_macro PRINTER_PARAM'].fan2_min) / 2 %}
    #     {% set tmp = printer['gcode_macro PRINTER_PARAM'].fan2_min + (255 - printer['gcode_macro PRINTER_PARAM'].fan2_min) / 2 %}
    #     SET_PIN PIN=fan2 VALUE={tmp}
    #   {% endif %}

      SET_GCODE_VARIABLE MACRO=Qmode VARIABLE=flag VALUE=1
      SET_QMODE_FLAG FLAG=1
    {% endif %}
  {% endif %}

[gcode_macro Qmode_exit]
gcode:
  {% set printer_state = printer.print_stats.state %}
  {% if printer['gcode_macro Qmode'].flag|int == 1 %}
    {% if printer_state == "printing" or printer_state == "paused" %}
      SET_VELOCITY_LIMIT ACCEL={printer['gcode_macro Qmode'].accel}
      SET_VELOCITY_LIMIT ACCEL_TO_DECEL={printer['gcode_macro Qmode'].accel_to_decel}
      SET_VELOCITY_LIMIT VELOCITY={printer['gcode_macro Qmode'].velocity}
      SET_VELOCITY_LIMIT SQUARE_CORNER_VELOCITY={printer['gcode_macro Qmode'].square_corner_velocity}
      SET_PRESSURE_ADVANCE ADVANCE={printer['gcode_macro Qmode'].pressure_advance}
      M220 S{printer['gcode_macro Qmode'].speed_factor * 100}
      
      {% set X_RUN_CUR = printer.configfile.settings['tmc2209 stepper_x'].run_current %}
      {% set Y_RUN_CUR = printer.configfile.settings['tmc2209 stepper_y'].run_current %}
      SET_TMC_CURRENT STEPPER=stepper_x CURRENT={X_RUN_CUR}
      SET_TMC_CURRENT STEPPER=stepper_y CURRENT={Y_RUN_CUR}

      SET_TMC_FIELD STEPPER=stepper_x FIELD=en_spreadcycle VALUE=1
      SET_TMC_FIELD STEPPER=stepper_y FIELD=en_spreadcycle VALUE=1 
      G4 P1000

      SET_GCODE_VARIABLE MACRO=Qmode VARIABLE=flag VALUE=0
      SET_QMODE_FLAG FLAG=0

      {% if printer['output_pin fan0'].value != 0 %}
        {action_respond_info("fan0_value = %s" % printer['gcode_macro Qmode'].fan0_value)}
        SET_PIN PIN=fan0 VALUE={printer['gcode_macro Qmode'].fan0_value}
        SET_GCODE_VARIABLE MACRO=Qmode VARIABLE=fan0_value VALUE=0
      {% endif %}
    #   {% if printer['output_pin fan1'].value != 0 %}
    #     {action_respond_info("fan1_value = %s" % printer['gcode_macro Qmode'].fan1_value)}
    #     SET_PIN PIN=fan1 VALUE={printer['gcode_macro Qmode'].fan1_value}
    #     SET_GCODE_VARIABLE MACRO=Qmode VARIABLE=fan1_value VALUE=0
    #   {% endif %}
    #   {% if printer['output_pin fan2'].value != 0 %}
    #     {action_respond_info("fan2_value = %s" % printer['gcode_macro Qmode'].fan2_value)}
    #     SET_PIN PIN=fan2 VALUE={printer['gcode_macro Qmode'].fan2_value}
    #     SET_GCODE_VARIABLE MACRO=Qmode VARIABLE=fan2_value VALUE=0
    #   {% endif %}
    {% endif %}
  {% endif %}
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

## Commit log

2025-09-09 Update spray_head_control.ino
    reversed sprayhead write ON/OFF:
    if M106 V > 3 then write A_ON
    else then A_OFF
    [spray_head_control.ino]
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2025-10-01 Update spray_head_control.ino
    flipped on/off angles
    off angle 60 -> 25
    [spray_head_control.ino]
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2025-11-18 Adjust spray job parameters and logic
    Updated spray job parameters and logic for better control.
    [spray_test.cfg]
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2025-11-18 Refactor airbrush macros for spray job control
    Updated airbrush macro configuration with enhanced spray job macros, including pause, resume, and stop functionalities. Improved alignment storage and validation for spray area setup.
    [airbrush_macro.cfg]
2025-11-18 Update parameter types to int in spray macros
    Changed parameter types from float to int for consistency and improved range calculations in macros.
    [spray_test.cfg]
2025-11-18 Modify default layers and completion message
    Changed default layer count from 4 to 1 and updated completion message.
    [spray_test.cfg]
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2026-05-01 Fix laser alignment re-run coordinate drift and MOVE_TO_LASER_ZERO target
    - Replace faulty G92 restore logic (which compounded offsets on re-run) with
    a physical-position reset so the coordinate system is cleanly zeroed before
    each alignment pass
    - Fix MOVE_TO_LASER_ZERO to move the nozzle to (offset_x, offset_y) so the
    laser crosshair lands on the spray BL corner (0,0) instead of using stale
    pre-G92 laser_x_pos/laser_y_pos values that caused out-of-range moves
    [aurora_laser.cfg]
2026-05-01 fix out of range issue with re-running laser alignment
    [aurora_laser.cfg]
2026-05-01 updated speed parameters to be defined as mm/s instead of mm/min.
    comments including the units at each set line
    [aurora_laser.cfg, aurora_spray.cfg, aurora_spray_zigzag.cfg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]
2026-05-01 fixed misc errors
    [aurora_spray.cfg, aurora_spray_zigzag.cfg]
2026-05-01 reorganized file location of movement macros
    renamed aurora_positions.cfg to aurora_move_to.cfg
    updated printer.cfg
    [aurora_laser.cfg, aurora_move_to.cfg, aurora_spray.cfg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]
2026-05-01 refactor spray loop to delayed_gcode, add stop support and area offset calibration
    - Restructure RUN_SPRAY_JOB and RUN_SPRAY_JOB_ZIGZAG as delayed_gcode loop chains
    so STOP_SPRAY can halt after current pass completes
    - Add SPRAY_STATE variable macro for shared job state (pass counter, params, stop flag)
    - Add SPRAY_JOB_NEXT_PASS and [delayed_gcode spray_job_loop] to drive per-pass execution
    - Update STOP_SPRAY to set stop flag and turn off fan immediately
    - Add ADJUST_SPRAY_AREA macro to aurora_calibrations.cfg for per-edge mm offsets
    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
    [aurora_calibrations.cfg, aurora_laser.cfg, aurora_move_to.cfg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]
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2026-05-01 fix MOVE_TO_INK_FILL_POSITION for laser-aligned coordinates, rename ADJUST_SPRAY_AREA
    - MOVE_TO_INK_FILL_POSITION now stores physical coordinates as variables and applies
    gcode_move.homing_origin offset at runtime so the same physical position is always reached
    regardless of laser alignment G92 offset
    - Rename ADJUST_SPRAY_AREA to ADJUST_SIDE_OFFSETS in aurora_calibrations.cfg
    [aurora_move_to.cfg]
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2026-05-01 replace SET_DISPLAY_PROGRESS with M73 — not a valid Klipper command
    [aurora_laser.cfg]
2026-05-01 fix max_accel_to_decel and MOVE_TO_INK_FILL_POSITION coordinate offset
    [printer.cfg]
2026-05-01 fix ink fill position to valid physical coordinates X164 Y10 Z100
    [aurora_move_to.cfg]
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2026-05-01 remove M73 progress commands — causes parse error in Klipper
    [aurora_spray.cfg]
2026-05-01 fix MOVE_TO_INK_FILL_POSITION G92 offset — use gcode_position - toolhead.position
    homing_origin is the endstop position, not the G92 offset
    [aurora_move_to.cfg]
2026-05-01 Fix LASER_AREA_SCAN_EDGES to use G90 absolute coords via laser-nozzle offset
    Replaced G91 relative moves (which caused out-of-range errors depending on
    toolhead start position) with G90 absolute moves that compute nozzle positions
    from the stored laser alignment offset, matching how LASER_ALIGNMENT_FROM_BL_CORNER works.
    [aurora_laser.cfg]
2026-05-01 Make LASER_AREA_SCAN_EDGES live-adjustable from ADJUST_SIDE_OFFSETS
    Scan loop now reads x_left/x_right/y_bottom/y_top directly from
    SPRAY_AREA_DEFAULTS on every tick, so ADJUST_SIDE_OFFSETS changes
    are picked up immediately without a separate sync step.
    Removed redundant area_x/area_y variables and the SET_GCODE_VARIABLE
    lines that mirrored them from ADJUST_SIDE_OFFSETS.
    [aurora_calibrations.cfg, aurora_laser.cfg]
2026-05-01 Remove stale area_x/area_y SET_GCODE_VARIABLE from SET_SPRAY_AREA_SIZE
    LASER_AREA_SCAN_EDGES no longer has these variables — it reads bounds
    directly from SPRAY_AREA_DEFAULTS. Setting them caused an unknown variable error.
    [aurora_laser.cfg]
2026-05-01 Make alignment and scan edge traces respect SET_SPRAY_AREA_SIZE
    LASER_ALIGNMENT_FROM_BL_CORNER now reads x_right/y_top from
    SPRAY_AREA_DEFAULTS for both the laser and nozzle trace squares
    instead of hardcoding 22mm. LASER_AREA_SCAN_EDGES already reads
    from SPRAY_AREA_DEFAULTS, so SET_SPRAY_AREA_SIZE now drives all three.
    [aurora_laser.cfg]
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2026-05-13 Add edge_speed_mult to spray zigzag passes
    Each zigzag pass now sprays the outer edge at a faster speed (default 1.5x)
    to compensate for the nozzle dwelling longer at edges during direction changes.
    Also reorder M106 S0 / reposition moves so spray stops before repositioning.
    [aurora_spray.cfg, aurora_spray_zigzag.cfg]
2026-05-13 apply set area and offsets to spray zz individual paths. also fix edge speed bug
    [aurora_spray.cfg, aurora_spray_zigzag.cfg]
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2026-06-02 Persist homing state and laser offset across restarts
    - Add SAVE_VARIABLES configuration to store state persistently
    - Create gcode_macro.cfg with startup restoration logic
    - Update laser alignment macros to save state automatically
    - Restore homing XY and all laser calibration data on boot
    - Eliminates need to re-home and re-align after code updates
    [aurora_calibrations.cfg, aurora_laser.cfg, aurora_spray.cfg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]
2026-06-02 Add STOP_RUN macro and respect stop flag in spray passes
    - Add STOP_RUN macro for immediate stop mid-pass (cannot resume)
    - Update all spray pass macros to check stop_requested flag
    - Allows interrupting spray job immediately vs waiting for pass completion
    [aurora_spray.cfg, aurora_spray_zigzag.cfg]
2026-06-02 Remove unsupported {% break %} statements from Jinja2 templates
    Jinja2 doesn't support break statements in loops. Loops will naturally skip
    when pause/stop is requested via the conditional checks.
    [aurora_spray.cfg, aurora_spray_zigzag.cfg, printer.cfg]
2026-06-02 Add pause/resume/stop functionality and standard Klipper macros
    - Add PAUSE_SPRAY, RESUME_SPRAY, and STOP_RUN macros for spray jobs
    - Add mid-pass pause/stop checks to all spray pass macros
    - Add standard pause, resume, and cancel_print Klipper macros
    - Pause/stop moves to ink fill position instead of bottom left corner
    [gcode_macro.cfg]
2026-06-02 Replace M106 commands with SET_PIN for spray control
    [aurora_spray.cfg, aurora_spray_zigzag.cfg]
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2026-06-02 Fix startup state restoration with proper variable defaults
    - Add fallback defaults to prevent undefined variable errors
    - Remove SET_KINEMATIC_POSITION which caused movement issues
    - Spray area safely defaults to 0,0->22,22 on first boot
    - Variables restored after all macros are loaded
    [gcode_macro.cfg]
2026-06-02 Remove restart-persistence code
    Removes [save_variables] section from printer.cfg, the
    [delayed_gcode restore_state_on_startup] block from gcode_macro.cfg,
    all SAVE_VARIABLE calls from aurora_laser.cfg and aurora_calibrations.cfg,
    and deletes aurora_spray_calibration.cfg.
    [aurora_calibrations.cfg, aurora_laser.cfg, aurora_spray_calibration.cfg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]
2026-06-02 Remove PAUSE/RESUME/CANCEL_PRINT wrappers from gcode_macro.cfg
    These rename_existing wrappers conflict with Creality's printer_params.cfg
    which already defines them. Spray macros use PAUSE_SPRAY/RESUME_SPRAY
    so these wrappers were not needed.
    [gcode_macro.cfg]
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2026-06-02 Redesign spray passes for mid-pass pause support
    Replace for-loop pattern (which Klipper evaluates all at once at template
    time) with a delayed_gcode line-by-line loop. SPRAY_NEXT_LINE executes
    one line per 50ms tick and checks pause_requested/stop_requested between
    each line, giving ~50ms pause response instead of waiting for the full
    pass to complete.
    Also adds pass_in_progress flag so RESUME_SPRAY restarts the correct
    loop (line loop if mid-pass, job loop if between passes), and clears
    pause_requested on RUN_SPRAY_JOB/RUN_SPRAY_JOB_ZIGZAG start.
    [aurora_spray.cfg, aurora_spray_zigzag.cfg]
2026-06-03 when resuming pass after pause, wait to start spraying until the nozzle is at the correct resume position.
    [aurora_spray.cfg, aurora_spray_zigzag.cfg]
2026-06-03 Enable pause/resume/stop for standalone individual spray macros
    Each pass macro now writes job_type, step, speed, and z into SPRAY_STATE
    before starting the line loop. SPRAY_NEXT_LINE reads all four from state,
    so without this they would use stale values from the previous job when a
    pass macro is called standalone — causing wrong line positions, wrong Z
    height, and the zigzag macros using the regular motion pattern instead of
    the diagonal one.
    [aurora_spray.cfg, aurora_spray_zigzag.cfg]
2026-06-03 Pause holds position; resume continues from where it stopped
    PAUSE_PASS no longer lifts Z or moves to the ink fill position — it just
    stops the spray and stays put. RESUME_PASS no longer sets pass_resuming,
    so the line loop restarts from the nozzle's current position rather than
    repositioning to the line start. Removed the now-dead pass_resuming block
    from SPRAY_NEXT_LINE and its variable from SPRAY_STATE.
    [aurora_spray.cfg]
2026-06-03 inverted Z axis movement direction in mailsail control buttons.
    UP now moves base up
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2026-06-03 Fix LASER_AREA_SCAN_EDGES not restarting after stop
    The persisted stop_requested flag stayed 1 after LASER_AREA_SCAN_STOP and
    was never cleared, so subsequent scans skipped all motion. Distinguish a
    fresh operator start (bare call) from a loop iteration (CONTINUE=1 from
    laser_area_scan_loop): a fresh start clears the flag, continuations respect
    it. Race-free since the flag is only cleared on the deliberate start.
    [aurora_laser.cfg]
2026-06-03 Remove non-functional save_variables persistence (unsupported on K1C firmware)
    The running firmware has no save_variables module, so every SAVE_VARIABLE
    call raised 'Unknown command' and the boot-time restore_state_on_startup
    macro (which read printer.save_variables.variables) could not work.
    Remove the [save_variables] section, the restore_state_on_startup macro,
    and all SAVE_VARIABLE calls. Alignment, laser-offset calibration, and
    spray-area settings now live only in the existing in-memory
    SET_GCODE_VARIABLE state and reset on restart. Origin restore is
    unaffected; restore_spray_origin_startup self-starts via its own
    initial_duration.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
    [aurora_calibrations.cfg, aurora_laser.cfg, gcode_macro.cfg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]
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2026-06-26 Fix edge offsets not applied to zigzag spray macros from Mainsail
    Mainsail passes empty strings for macro param fields left blank. The
    prior `params.X_LEFT is defined` guard treated empty strings as valid
    values, so `""|int = 0` silently overrode the SPRAY_AREA_DEFAULTS
    boundaries set by ADJUST_SIDE_OFFSETS — matching the hardcoded 0/22
    defaults rather than the adjusted area the laser scan was showing.
    Two fixes:
    1. Guard now also rejects empty string: `is defined and != ""`
    so blank Mainsail fields fall through to live SPRAY_AREA_DEFAULTS.
    2. SPRAY_JOB_NEXT_PASS reads zigzag boundaries from SPRAY_AREA_DEFAULTS
    directly (like LASER_AREA_SCAN_EDGES does) rather than the snapshot
    i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
    [aurora_spray.cfg, aurora_spray_zigzag.cfg]
2026-06-27 Increase responsiveness of spray pause/stop macros
    Two issues fixed:
    1. Mid-pass pause/stop lag — Jinja2 {% if %} checks inside for-loops
    are rendered once at macro invocation, so pause/stop flags set while
    moves are executing were invisible until the entire pass finished.
    Fix: extract per-stripe logic into SPRAY_STRIPE_H / SPRAY_STRIPE_V
    (and ZZ variants) helper macros. Each stripe is queued as a separate
    GCode macro dispatch, which re-renders and re-reads the flags at
    execution time. Worst-case lag is now one stripe's worth of movement
    (~2 s at 50 mm/s over 22 mm) instead of the full remaining pass.
    2. STOP dry-time lag — calling STOP while between passes left th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
    [aurora_spray.cfg, aurora_spray_zigzag.cfg]
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2026-07-17 added missing printer params
    restored printer_params.cfg and added variable max_x/y/z_position to gcode_macro.cfg
    [gcode_macro.cfg, printer_params.cfg]
2026-07-17 the pause and stop are working fast now. however the indivdual spray macros were held up by stop flag from the last commit. fixed
    [aurora_laser.cfg, aurora_spray.cfg, aurora_spray_zigzag.cfg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]
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
